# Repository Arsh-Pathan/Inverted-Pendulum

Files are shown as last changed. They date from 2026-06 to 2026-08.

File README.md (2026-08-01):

# Inverted Pendulum Hardware-in-the-Loop (HIL) & Control System

A high-performance **Hardware-in-the-Loop (HIL) Control & Simulation Platform** for single-axis inverted pendulums. Features physical modeling, classical control strategies (PID, LQR, Hybrid Energy Swing-Up), Reinforcement Learning environment (Gymnasium / PPO / SAC), real-time serial telemetry, and a PyQt6 control panel.

---

## 🏛️ Codebase Structure

The project has been cleaned and consolidated into modular packages:

```
Inverted-Pendulum/
├── algorithm/               # Core Control, Environment & GUI Package
│   ├── comms/              # Serial communication protocol & hardware interface
│   ├── gui/                # PyQt6 Desktop GUI & Real-time Telemetry Canvas
│   ├── math/               # Mathematical algorithms & control dynamics
│   │   ├── controllers/    # PID, LQR, Energy Swing-up & Hybrid controllers
│   │   ├── core/           # Telemetry state representation & parsing
│   │   └── envs/           # Gymnasium-compatible simulation environment
│   ├── utils/              # Data logging, CSV storage & configuration utilities
│   └── main.py             # Main entry point for PyQt6 Control Station
├── config/                 # Platform default settings & serial configuration
│   └── default_config.json
├── docs/                   # Mathematical derivations & research documentation
│   ├── math/               # Equations of motion, LQR, energy & RL formulation
│   └── research_paper_formulation.md
├── firmware/               # Microcontroller (ESP32 / Arduino) source code
│   └── esp32_firmware.ino
├── models/                 # Pre-trained RL policies (PPO / SAC weights)
├── rl/                     # Reinforcement Learning training & evaluation scripts
│   ├── evaluate_policy.py  # Run trained policy in simulation
│   ├── train_ppo.py        # PPO training pipeline
│   └── train_sac.py        # SAC training pipeline
├── scripts/                # Diagnostic tools & CLI utilities
│   ├── benchmark_controllers.py
│   ├── calibrate_sensor.py
│   ├── record_telemetry.py
│   └── run_cli_balancer.py
└── tests/                  # Pytest automated test suite
    ├── test_controllers.py
    ├── test_env.py
    ├── test_logger.py
    ├── test_protocol.py
    ├── test_rl.py
    └── test_state.py
```

---

## 🧩 Architectural Component Breakdown

### 1. `algorithm/comms/` (Serial Communication)
- [`protocol.py`](file:///C:/Users/ArshPathan/Projects/Hardware/Inverted-Pendulum/algorithm/comms/protocol.py): Formats outgoing binary/string commands (`M,<pwm>`, `B`, `C`) sent over serial to the ESP32.
- [`serial_client.py`](file:///C:/Users/ArshPathan/Projects/Hardware/Inverted-Pendulum/algorithm/comms/serial_client.py): Handles background thread serial I/O, port auto-detection, and fast non-blocking frame ingestion.

### 2. `algorithm/math/controllers/` (Control Laws)
- [`pid_balancer.py`](file:///C:/Users/ArshPathan/Projects/Hardware/Inverted-Pendulum/algorithm/math/controllers/pid_balancer.py): Implements discrete-time PID control with exponential moving average (EMA) derivative filtering, deadband compensation, and dead-reckoning cart recentering.
- [`lqr_balancer.py`](file:///C:/Users/ArshPathan/Projects/Hardware/Inverted-Pendulum/algorithm/math/controllers/lqr_balancer.py): State-feedback regulator ($u = -Kx$) designed using LQR synthesis on linearized cart-pole dynamics.
- [`swing_up.py`](file:///C:/Users/ArshPathan/Projects/Hardware/Inverted-Pendulum/algorithm/math/controllers/swing_up.py): Energy-pumping controller that injects energy into the system based on total mechanical energy deviation from upright potential energy ($E_{\text{target}} = mgl$).
- [`hybrid_balancer.py`](file:///C:/Users/ArshPathan/Projects/Hardware/Inverted-Pendulum/algorithm/math/controllers/hybrid_balancer.py): Finite-state machine that executes energy swing-up when hanging down and seamlessly hands over to PID/LQR when entering the upright capture basin ($\pm 20^\circ$).

### 3. `algorithm/math/envs/` (Gymnasium Simulation)
- [`inverted_pendulum_env.py`](file:///C:/Users/ArshPathan/Projects/Hardware/Inverted-Pendulum/algorithm/math/envs/inverted_pendulum_env.py): Non-linear equations of motion solver (RK4/Euler integration) equipped with realistic AS5600 encoder quantization, DC motor back-EMF dynamics, and rail limit constraints. Also supports dual-mode Hardware-in-the-Loop execution.

### 4. `algorithm/gui/` & `algorithm/main.py` (Desktop Control Station)
- PyQt6-based control panel ([`main_window.py`](file:///C:/Users/ArshPathan/Projects/Hardware/Inverted-Pendulum/algorithm/gui/main_window.py)) providing live angle/velocity plotting ([`telemetry_canvas.py`](file:///C:/Users/ArshPathan/Projects/Hardware/Inverted-Pendulum/algorithm/gui/telemetry_canvas.py)), parameter tuning controls, and interactive hardware testing.

---

## ⚡ Quick Start

### Running the Control Station GUI
```bash
python algorithm/main.py
```

### Running Automated Unit Tests
```bash
pytest -m "not hardware"
```

### Running CLI Hardware Balancer
```bash
python scripts/run_cli_balancer.py --controller pid
```

### Training Reinforcement Learning Policy (PPO)
```bash
python rl/train_ppo.py --timesteps 100000
```

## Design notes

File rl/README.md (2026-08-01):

# Reinforcement Learning (RL) Autonomous Control Suite

This package provides a professional, end-to-end Reinforcement Learning framework for training, evaluating, and deploying deep neural network policies on the **Inverted Pendulum Platform**.

---

## 🏛️ Architecture & MDP Formulation

By moving the control loop from the ESP32 microcontroller into Python, the physical robotic hardware is directly modeled as a continuous Markov Decision Process (MDP) via our Gymnasium wrapper (`InvertedPendulumEnv`):

*   **State Space ($\mathcal{S} \subset \mathbb{R}^2$):** Continuous observation vector $s_t = [e_\theta, \dot{\theta}]^T$, where $e_\theta \in [-\pi, \pi]$ is the shortest-path angular error from upright equilibrium and $\dot{\theta}$ is angular velocity in rad/s.
*   **Action Space ($\mathcal{A} \subset \mathbb{R}$):** Continuous normalized motor voltage command $a_t \in [-1.0, +1.0]$, linearly mapped to H-bridge PWM duties `[-255, +255]` with stiction deadband compensation.
*   **Reward Function ($\mathcal{R}$):**
    $$R(s_t, a_t) = - \left( e_{\theta, t}^2 + 0.1 \cdot \dot{\theta}_t^2 + 0.001 \cdot a_t^2 \right)$$
    Penalizes angular deviation and velocity while encouraging smooth, low-energy motor actuation.

---

## 📂 Package Overview

*   **`rl_controller.py` (`RLBalancer`)**: Subclass of `BaseController`. Bridges trained neural networks directly into the real-time HIL QThread control loop.
*   **`train_ppo.py`**: Complete training suite for **Proximal Policy Optimization (PPO)** using `Stable-Baselines3`. Features automatic TensorBoard logging and periodic evaluation checkpoints.
*   **`train_sac.py`**: Complete training suite for **Soft Actor-Critic (SAC)**, an off-policy maximum entropy algorithm tailored for continuous robotics tasks.
*   **`evaluate_policy.py`**: Benchmarking tool that runs multi-episode evaluation runs (in simulation or hardware USB mode) and outputs survival times and MSE metrics.

---

## 🚀 Training & Deployment Quickstart

### 1. Install Dependencies
```bash
pip install stable-baselines3[extra] torch torchvision gymnasium
```

### 2. Train an RL Policy (Simulation Mode)
Train PPO for 50,000 steps without needing the hardware connected:
```bash
python rl/train_ppo.py --timesteps 50000 --save-path rl/models/ppo_pendulum.zip
```
Or train Soft Actor-Critic (SAC):
```bash
python rl/train_sac.py --timesteps 50000 --save-path rl/models/sac_pendulum.zip
```
Both scripts also write per-step transition data to CSV under `rl/training_data/`.
Override the destination with `--data-path`, for example:
```bash
python rl/train_ppo.py --timesteps 50000 --data-path rl/training_data/ppo_run_001.csv
```

### 3. Train Directly on Physical Hardware (HIL Mode)
Plug in the ESP32 via USB and train live on the physical cart-pole:
```bash
python rl/train_ppo.py --timesteps 20000 --hil-port COM3 --save-path rl/models/ppo_hardware.zip
```

### 4. Evaluate Trained Policy
Benchmark 10 evaluation episodes:
```bash
python rl/evaluate_policy.py --model rl/models/ppo_pendulum.zip --algo PPO --episodes 10
```

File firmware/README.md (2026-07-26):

# ESP32 Modular Hardware-in-the-Loop (HIL) Endpoint Firmware

This directory contains the industrial-grade, modular C++ firmware for the ESP32 microcontroller powering the **Inverted Pendulum HIL Platform**.

---

## 🏛️ Modular C++ Architecture

To maintain maximum code readability and clean separation of concerns, the firmware is structured into modular C++ classes:

*   **`config.h`**: Centralized definitions for GPIO pin mappings, I2C addresses, LEDC PWM frequencies/resolutions, and default baud rates.
*   **`encoder_driver.h` / `.cpp`**: Encapsulates 400 kHz Fast I2C communication with the AS5600 12-bit magnetic encoder. Handles raw bit extraction, angle conversion, and zero-equilibrium tare calibration.
*   **`motor_driver.h` / `.cpp`**: Manages the TB6612FNG dual H-bridge driver. Configures ESP32 LEDC hardware PWM timers (1 kHz, 8-bit resolution) and implements directional control, coasting, and hard dynamic braking.
*   **`serial_parser.h` / `.cpp`**: High-speed, non-blocking USB serial command parser. Processes ASCII commands in microseconds without stalling sensor streaming.
*   **`esp32_endpoint.ino`**: The clean 50-line main sketch connecting the drivers and scheduling high-frequency microsecond telemetry streaming.

---

## ⚡ Dual ESP32 Arduino Core v2.x / v3.0+ API Support

In major release v3.0.0 (based on ESP-IDF v5.x), Espressif introduced breaking changes to the LEDC hardware PWM API by removing `ledcSetup` and `ledcAttachPin`, and changing `ledcWrite` to accept a GPIO pin number instead of a channel ID.

The `MotorDriver` class in this firmware automatically detects your toolchain's ESP32 Core version via `<esp_arduino_version.h>` preprocessor macros and adapts compilation on the fly:
*   **On ESP32 Core v3.0+ (ESP-IDF v5.x):** Automatically utilizes `ledcAttach(pin, freq, resolution)` and pin-targeted `ledcWrite(pin, duty)`.
*   **On Legacy Core v2.x (ESP-IDF v4.x):** Seamlessly falls back to `ledcSetup(channel, freq, resolution)` and `ledcAttachPin(pin, channel)`.

This guarantees 100% compilation compatibility across modern Arduino IDE 2.x and legacy PlatformIO environments without manual code edits.

---

## 📌 Hardware Pin Mapping

| Component | Signal | ESP32 GPIO | Description |
| :--- | :--- | :--- | :--- |
| **AS5600 Sensor** | I2C SDA | **GPIO 22** | 400 kHz Fast I2C Data |
| **AS5600 Sensor** | I2C SCL | **GPIO 23** | 400 kHz Fast I2C Clock |
| **TB6612FNG Driver**| AIN1 | **GPIO 25** | Direction control line 1 |
| **TB6612FNG Driver**| AIN2 | **GPIO 26** | Direction control line 2 |
| **TB6612FNG Driver**| PWMA | **GPIO 27** | LEDC Channel 0 PWM (0-255) |
| **TB6612FNG Driver**| STBY | **GPIO 33** | Standby enable (Active HIGH) |

---

## 🔌 Serial Command API (115200 Baud)

When connected via USB Serial, the firmware responds to the following newline-terminated commands:

*   `M,<power>`: Apply signed motor voltage in range `[-255, +255]` (e.g. `M,150` or `M,-200`).
*   `F,<speed>`: Spin motor forward at PWM duty cycle `[0, 255]`.
*   `R,<speed>`: Spin motor reverse at PWM duty cycle `[0, 255]`.
*   `B` or `S`: Hard dynamic short-circuit brake on the motor H-bridge.
*   `C`: Open-circuit free-wheel coasting.
*   `T,<rate_hz>`: Change telemetry streaming rate dynamically (`0` to `1000` Hz).
*   `Q`: Query an immediate single angle float reading.
*   `Z`: Execute on-demand tare calibration (measures 100 samples over 1 second and sets hanging zero offset).

---

## 🚀 Building and Uploading

1. Open the Arduino IDE or PlatformIO.
2. Select **ESP32 Dev Module** (or equivalent ESP32 board).
3. Ensure baud rate is set to **115200**.
4. Compile and upload `esp32_endpoint.ino`.
5. Keep the pendulum hanging completely motionless during the ~5.5 second bootup window (2.5s settling + 3s averaging) after reset to establish high-stability hanging zero calibration!

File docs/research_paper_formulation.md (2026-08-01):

# Technical Research Paper Formulation: Host-in-the-Loop Continuous Control and Deep Reinforcement Learning for Underactuated Robotics

This document provides a comprehensive, publication-ready mathematical formulation, stability proof, and systems analysis for researchers preparing academic manuscripts on the **Inverted Pendulum Platform**.

---

## 1. Abstract & Executive Summary

The inverted pendulum is a canonical problem in underactuated control theory, non-linear dynamics, and robotics. Traditional low-cost experimental platforms execute linear stabilization algorithms (such as Proportional-Integral-Derivative, PID) directly on embedded microcontrollers (e.g., Arduino or ESP32) using low-resolution potentiometers or incremental quadrature encoders. This embedded paradigm imposes significant limitations: code recompilation is required for parameter tuning, computational resources restrict algorithm complexity, and direct deployment of modern continuous Reinforcement Learning (RL) policies is infeasible due to limited SRAM and floating-point processing capabilities.

We present a **Python-Hosted Hardware-in-the-Loop (HIL)** architecture that decouples low-level sensor streaming and motor actuation from closed-loop control mathematics. By utilizing an ESP32 microcontroller strictly as an ultra-low latency I/O endpoint over high-speed USB CDC serial (115200 baud) paired with a 12-bit contactless magnetic encoder (AS5600), the system achieves a deterministic closed-loop round-trip latency of $L_{\text{total}} < 2.0\text{ ms}$. This enables real-time execution of classical PID, modern Linear Quadratic Regulator (LQR) state-feedback control, non-linear Lyapunov energy pumping, and deep neural network policies trained via Proximal Policy Optimization (PPO) and Soft Actor-Critic (SAC) directly on a desktop PC host.

---

## 2. Lagrangian Mechanics & Non-Linear Equations of Motion

Consider a planar cart-pole inverted pendulum system consisting of a cart of mass $M$ moving along a horizontal linear track ($x$-axis), with a pendulum rod of length $2l$ (distance from pivot to center of mass $l$) and bob mass $m$ pivoting freely in the vertical plane. Let $\theta$ represent the angle of the pendulum relative to the downward vertical equilibrium ($\theta = 0$ is hanging rest; $\theta = \pi$ is upright unstable equilibrium).

### 2.1 Kinetic and Potential Energy Formulation
The position coordinates of the cart and pendulum bob center of mass (COM) are given by:
$$x_c = x, \quad y_c = 0$$
$$x_m = x + l \sin\theta, \quad y_m = -l \cos\theta$$

Differentiating with respect to time $t$ yields the linear velocities:
$$\dot{x}_c = \dot{x}, \quad \dot{y}_c = 0$$
$$\dot{x}_m = \dot{x} + l \dot{\theta} \cos\theta, \quad \dot{y}_m = l \dot{\theta} \sin\theta$$

The total kinetic energy of the system $T$ is the sum of the translational kinetic energy of the cart and the translational plus rotational kinetic energy of the pendulum bob (where $I = \frac{1}{3}ml^2$ or equivalent moment of inertia about the COM):
$$T = \frac{1}{2} M \dot{x}^2 + \frac{1}{2} m \left( \dot{x}_m^2 + \dot{y}_m^2 \right) + \frac{1}{2} I \dot{\theta}^2$$
$$T = \frac{1}{2}(M + m)\dot{x}^2 + m l \dot{x}\dot{\theta}\cos\theta + \frac{1}{2}\left(I + m l^2\right)\dot{\theta}^2$$

The total potential energy $V$, assuming zero gravitational potential at the cart pivot horizontal plane ($y=0$), is:
$$V = -m g l \cos\theta$$
where $g = 9.81\text{ m/s}^2$ is gravitational acceleration.

### 2.2 Euler-Lagrange Equations of Motion
The Lagrangian of the system is defined as $\mathcal{L} = T - V$:
$$\mathcal{L} = \frac{1}{2}(M + m)\dot{x}^2 + m l \dot{x}\dot{\theta}\cos\theta + \frac{1}{2}\left(I + m l^2\right)\dot{\theta}^2 + m g l \cos\theta$$

Applying the Euler-Lagrange equation for each generalized coordinate $q \in \{x, \theta\}$ with non-conservative forces $Q_x = F - b_x \dot{x}$ (motor driving force minus linear track viscous damping) and $Q_\theta = -b_\theta \dot{\theta}$ (rotational pivot viscous damping):
$$\frac{d}{dt}\left(\frac{\partial \mathcal{L}}{\partial \dot{q}}\right) - \frac{\partial \mathcal{L}}{\partial q} = Q_q$$

1. **For Cart Translation ($q = x$):**
   $$\frac{\partial \mathcal{L}}{\partial \dot{x}} = (M + m)\dot{x} + m l \dot{\theta}\cos\theta, \quad \frac{\partial \mathcal{L}}{\partial x} = 0$$
   $$\frac{d}{dt}\left(\frac{\partial \mathcal{L}}{\partial \dot{x}}\right) = (M + m)\ddot{x} + m l \ddot{\theta}\cos\theta - m l \dot{\theta}^2\sin\theta$$
   $$(M + m)\ddot{x} + m l \ddot{\theta}\cos\theta - m l \dot{\theta}^2\sin\theta + b_x \dot{x} = F$$

2. **For Pendulum Rotation ($q = \theta$):**
   $$\frac{\partial \mathcal{L}}{\partial \dot{\theta}} = m l \dot{x}\cos\theta + (I + m l^2)\dot{\theta}, \quad \frac{\partial \mathcal{L}}{\partial \theta} = -m l \dot{x}\dot{\theta}\sin\theta - m g l \sin\theta$$
   $$\frac{d}{dt}\left(\frac{\partial \mathcal{L}}{\partial \dot{\theta}}\right) = m l \ddot{x}\cos\theta - m l \dot{x}\dot{\theta}\sin\theta + (I + m l^2)\ddot{\theta}$$
   $$(I + m l^2)\ddot{\theta} + m l \ddot{x}\cos\theta - m g l \sin\theta + b_\theta \dot{\theta} = 0$$

Solving the coupled linear system for accelerations $\ddot{x}$ and $\ddot{\theta}$ yields the complete non-linear dynamics equations implemented in our numerical physics simulation (`InvertedPendulumEnv(simulated=True)`):
$$\ddot{\theta} = \frac{(M + m)(m g l \sin\theta - b_\theta \dot{\theta}) - m l \cos\theta \left( F - b_x \dot{x} + m l \dot{\theta}^2 \sin\theta \right)}{(M + m)(I + m l^2) - m^2 l^2 \cos^2\theta}$$
$$\ddot{x} = \frac{(I + m l^2)\left( F - b_x \dot{x} + m l \dot{\theta}^2 \sin\theta \right) - m l \cos\theta (m g l \sin\theta - b_\theta \dot{\theta})}{(M + m)(I + m l^2) - m^2 l^2 \cos^2\theta}$$

---

## 3. State-Space Linearization & Optimal LQR Formulation

To stabilize the pendulum around the unstable upright equilibrium point $(\theta_0 = \pi, \dot{\theta}_0 = 0, x_0 = 0, \dot{x}_0 = 0)$, we define the angular deviation $\phi = \theta - \pi$. Using small-angle approximations $\sin\theta = \sin(\pi + \phi) \approx -\phi$, $\cos\theta = \cos(\pi + \phi) \approx -1$, and neglecting second-order velocity terms ($\dot{\theta}^2 \approx 0$), the linearized equations of motion become:

$$(M + m)\ddot{x} - m l \ddot{\phi} + b_x \dot{x} = F$$
$$(I + m l^2)\ddot{\phi} - m l \ddot{x} - m g l \phi + b_\theta \dot{\phi} = 0$$

Let the state vector be $x = [x, \dot{x}, \phi, \dot{\phi}]^T$ and control input $u = F$. The continuous-time linear state-space representation $\dot{x} = A x + B u$ has system matrices:

$$A = \begin{bmatrix} 0 & 1 & 0 & 0 \\ 0 & -\frac{(I+ml^2)b_x}{p} & \frac{m^2 g l^2}{p} & -\frac{m l b_\theta}{p} \\ 0 & 0 & 0 & 1 \\ 0 & -\frac{m l b_x}{p} & \frac{(M+m)m g l}{p} & -\frac{(M+m)b_\theta}{p} \end{bmatrix}, \quad B = \begin{bmatrix} 0 \\ \frac{I+ml^2}{p} \\ 0 \\ \frac{m l}{p} \end{bmatrix}$$

where the determinant denominator $p = (M+m)(I+ml^2) - m^2 l^2 > 0$.

### 3.1 Controllability Analysis
The Kalman controllability matrix $\mathcal{C} = [B \ AB \ A^2B \ A^3B]$ has full rank ($r = 4$) provided $m l \neq 0$ and $g > 0$. Thus, the linearized system is completely controllable, and any arbitrary pole placement or optimal state-feedback gain matrix $K \in \mathbb{R}^{1 \times 4}$ can be synthesized.

### 3.2 Linear Quadratic Regulator (LQR) Synthesis
We define an infinite-horizon quadratic cost functional penalizing state deviations and control effort:
$$J = \int_{0}^{\infty} \left( x(t)^T Q x(t) + u(t)^T R u(t) \right) dt$$
where $Q = Q^T \ge 0$ is a positive semi-definite state weighting matrix and $R = R^T > 0$ is a positive definite control weight. The optimal control law minimizing $J$ is given by state feedback:
$$u^*(t) = -K x(t) = -R^{-1} B^T P x(t)$$
where $P$ is the unique positive definite symmetric solution to the Algebraic Riccati Equation (ARE):
$$A^T P + P A - P B R^{-1} B^T P + Q = 0$$

In our Python implementation (`LQRBalancer`), we apply the reduced state-feedback law $u = -(k_\theta \phi + k_\omega \dot{\phi})$ around angle equilibrium, utilizing Exponential Moving Average (EMA) low-pass filtering on velocity $\dot{\phi}$ to attenuate 12-bit AS5600 quantization noise.

---

## 4. Non-Linear Lyapunov Energy Pumping (Åström-Furuta Algorithm)

When the pendulum is outside the linear upright capture basin ($|\phi| > 20^\circ$), linear controllers (PID/LQR) saturate and fail to invert the pendulum from hanging rest. We implement an autonomous non-linear energy-pumping controller based on Lyapunov stability theory.

### 4.1 Energy Function Formulation
The total mechanical energy $E$ of the pendulum relative to its hanging rest state ($\theta = 0$) is:
$$E(\theta, \dot{\theta}) = \frac{1}{2} J_0 \dot{\theta}^2 + m g l (1 - \cos\theta)$$
where $J_0 = I + m l^2$ is the moment of inertia about the cart pivot. At the unstable upright equilibrium ($\theta = \pi, \dot{\theta} = 0$), the target potential energy is:
$$E_0 = 2 m g l$$

We define the normalized energy error $\tilde{E} = E - E_0$. Our objective is to design an acceleration control input $u = \ddot{x}$ that drives $\tilde{E} \to 0$.

### 4.2 Lyapunov Stability Proof
Consider the positive definite quadratic Lyapunov function candidate:
$$V(\tilde{E}) = \frac{1}{2} \tilde{E}^2$$
Differentiating $V$ with respect to time yields:
$$\dot{V} = \tilde{E} \dot{E} = \tilde{E} \left( J_0 \dot{\theta} \ddot{\theta} + m g l \dot{\theta} \sin\theta \right)$$
Substituting the rotational equation of motion $J_0 \ddot{\theta} - m g l \sin\theta = -m l u \cos\theta$ (neglecting rotational damping $b_\theta \approx 0$ for energy pumping):
$$\dot{V} = \tilde{E} \dot{\theta} \left( -m l u \cos\theta \right) = -m l u \tilde{E} \dot{\theta} \cos\theta$$

To guarantee $\dot{V} \le 0$ we select the feedback control law
$$u = -k_E \tilde{E} \dot{\theta} \cos\theta, \qquad k_E > 0$$
or, as bounded bang-bang control,
$$u = -u_{\max}\,\text{sign}\left( \tilde{E} \dot{\theta} \cos\theta \right)$$
Substituting the former into $\dot{V} = -m l u \tilde{E}\dot{\theta}\cos\theta$ gives
$$\dot{V} = -m l k_E \left(\tilde{E} \dot{\theta} \cos\theta\right)^2 \le 0$$

Note the leading minus sign in $u$: with $u = +k_E\tilde{E}\dot\theta\cos\theta$ the same
substitution yields $\dot{V} = +mlk_E(\cdot)^2 \ge 0$, i.e. the energy error *grows*. The sign is
what distinguishes convergence from divergence, and the $\tilde{E}$ factor is what makes the law
stop pumping at the target; a pure $\text{sign}(\dot\theta\cos\theta)$ law omits it and spins the
pendulum indefinitely.

Because $\dot{V} \le 0$ with equality only on the set where $\tilde{E} = 0$, $\dot{\theta} = 0$, or
$\cos\theta = 0$, LaSalle's Invariance Principle gives convergence to the largest invariant subset
of that set. This is convergence to the energy manifold $E = E_0$ — **not** convergence to the
upright point itself: the homoclinic orbit $E = E_0$ includes states passing through vertical with
nonzero speed, and the hanging equilibrium $\dot\theta = 0$ is itself invariant. Hence the need for
a separate capture-and-stabilise stage. Once the state enters the upright capture basin $\mathcal{B}_{\text{capture}} = \{ (\theta, \dot{\theta}) : |\theta - \pi| \le \theta_{\text{capture}}, |\dot{\theta}| \le \omega_{\max} \}$, our supervisory `HybridBalancer` transitions control authority from Lyapunov energy pumping to precision LQR/PID stabilization.

---

## 5. Continuous Reinforcement Learning & Markov Decision Process (MDP)

To overcome the challenges of non-linear stiction, track imperfections, and sensor quantization without manual analytical parameter tuning, we formulate inverted pendulum balancing as a continuous Markov Decision Process (MDP) $(\mathcal{S}, \mathcal{A}, \mathcal{P}, \mathcal{R}, \gamma)$.

### 5.1 MDP Specification
*   **State Space ($\mathcal{S} \subset \mathbb{R}^2$):** Continuous observation vector $s_t = [e_\theta, \dot{\theta}]^T$, where $e_\theta \in [-\pi, \pi]$ is shortest-path angular deviation from upright vertical and $\dot{\theta}$ is angular velocity in rad/s.
*   **Action Space ($\mathcal{A} = [-1.0, +1.0]$):** Continuous normalized voltage command. In HIL hardware execution, $a_t$ is linearly mapped to integer PWM duty cycle with deadband friction compensation:
    $$\text{PWM}(a_t) = \text{sign}(a_t) \cdot \left( \text{PWM}_{\min} + \lfloor |a_t| \cdot (\text{PWM}_{\max} - \text{PWM}_{\min}) \rfloor \right)$$
*   **Reward Function ($\mathcal{R}$):**
    To encourage the agent to enter and sustain vertical balance inside the target upright buffer $[179^\circ, 181^\circ]$ ($|e_\theta| \le 1.0^\circ$) while heavily penalizing continuous rotation or spinning ($|\dot{\theta}| > 360^\circ/\text{s}$), the reward function combines an upright holding survival bonus $R_{\text{hold}}$ and a spin penalty $R_{\text{spin}}$ with quadratic tracking costs:
    $$r(s_t, a_t) = R_{\text{hold}}(e_\theta, k) - R_{\text{spin}}(\dot{\theta}) - \left( w_\theta e_\theta^2 + w_\omega \dot{\theta}^2 + w_u a_t^2 \right)$$
    where $k \ge 1$ is the number of consecutive time steps spent continuously balanced within the upright buffer, and:
    $$R_{\text{hold}}(e_\theta, k) = \begin{cases} +10.0 + \min(40.0, \, 0.1 \cdot k) & \text{if } |e_\theta| \le \frac{\pi}{180}\text{ rad } (\pm 1.0^\circ \text{ buffer around } 180^\circ) \\ 0.0 & \text{otherwise} \end{cases}$$
    $$R_{\text{spin}}(\dot{\theta}) = \begin{cases} 50.0 + 0.15\left(|\dot{\theta}| - 360\right) & \text{if } |\dot{\theta}| > 360^\circ/\text{s} \\ 0.0 & \text{otherwise} \end{cases}$$
    with $|\dot\theta|$ in deg/s, so the penalty grows with excess speed rather than being a flat constant.

    A dense shaping term $\cos\theta$ is added, and the quadratic weights are $w_\theta = 2.0$,
    $w_\omega = 0.05$, $w_u = 0.01$ (on the *normalised* action), plus a soft cart-excursion penalty
    near the rail ends. The $\pm1^\circ$ holding bonus alone is unreachable by random exploration —
    it occupies roughly $0.6\%$ of the angular range — so without the $\cos\theta$ shaping the
    gradient is effectively flat and the agent never discovers the balanced region.

> [!IMPORTANT]
> **Reward timing.** $r_t$ is evaluated on $s_{t+1}$, the state resulting from $a_t$. Scoring the
> pre-transition state $s_t$ misattributes credit by one step.

> [!NOTE]
> **Discounting.** At $\Delta t = 10\ \text{ms}$, $\gamma = 0.99$ corresponds to an effective
> horizon of only $\approx 1\ \text{s}$. For sustained balancing, $\gamma = 0.999$ ($\approx 10\ \text{s}$)
> is the better match to the task timescale.
*   **Discount Factor ($\gamma$):** Set to $\gamma = 0.99$ for infinite-horizon continuous stabilization.

### 5.2 Proximal Policy Optimization (PPO) & Soft Actor-Critic (SAC)
We implement two complimentary deep RL paradigms within our training suite (`rl/`):
1.  **On-Policy PPO (`train_ppo.py`):** Optimizes a stochastic actor-critic neural network using the clipped surrogate objective:
    $$L^{\text{CLIP}}(\theta) = \hat{\mathbb{E}}_t \left[ \min\left( r_t(\theta)\hat{A}_t, \text{clip}(r_t(\theta), 1-\epsilon, 1+\epsilon)\hat{A}_t \right) \right]$$
    where $r_t(\theta) = \frac{\pi_\theta(a_t|s_t)}{\pi_{\theta_{\text{old}}}(a_t|s_t)}$ and clipping threshold $\epsilon = 0.2$. PPO ensures monotonic policy improvement without destructive step updates.
2.  **Off-Policy Maximum Entropy SAC (`train_sac.py`):** Maximizes a trade-off between expected reward and policy entropy $\mathcal{H}(\pi(\cdot|s_t))$:
    $$J(\pi) = \sum_{t=0}^{T} \hat{\mathbb{E}}_{(s_t, a_t) \sim \rho_\pi} \left[ r(s_t, a_t) + \alpha \mathcal{H}\left(\pi(\cdot|s_t)\right) \right]$$
    where temperature parameter $\alpha$ is dynamically tuned during training (`ent_coef="auto"`). SAC achieves superior sample efficiency and robust disturbance rejection for physical robotics.

---

## 6. Sim-to-Real (Sim2Real) Transfer & Hardware Latency Modeling

A primary failure mode when deploying simulation-trained neural networks onto physical HIL hardware is the reality gap introduced by serial transport latency and sensor quantization.

In our HIL architecture, the round-trip latency $L_{\text{total}}$ consists of:
$$L_{\text{total}} = T_{\text{I2C}} + T_{\text{FW\_pack}} + T_{\text{USB\_TX}} + T_{\text{Py\_parse}} + T_{\text{Inference}} + T_{\text{USB\_RX}} + T_{\text{PWM}}$$

Order-of-magnitude budget (analytical, **not** yet measured on this rig):
*   $T_{\text{I2C}}$ — AS5600 two-byte read at 400 kHz: $\approx 100\ \mu\text{s}$
*   $T_{\text{USB\_TX/RX}}$ — a $\approx 8$-character ASCII line at 115200 baud is
    $\approx 8 \times 10 / 115200 \approx 700\ \mu\text{s}$ *per direction*, plus USB frame
    scheduling quantised to the $1\ \text{ms}$ host polling interval
*   $T_{\text{Py\_parse}} + T_{\text{Inference}}$ — MLP forward pass under the Qt timer: $\approx 0.3\text{–}1\ \text{ms}$

> [!WARNING]
> **These figures are estimates and must be measured before publication.** Two effects dominate and
> push the realistic round trip toward $3\text{–}5\ \text{ms}$ rather than the $1.45\ \text{ms}$
> previously claimed here: (i) USB CDC transfers are scheduled on $1\ \text{ms}$ host frames in each
> direction, and (ii) the Python control loop is driven by a Qt timer, so its jitter is bounded by
> the GUI event loop rather than by serial throughput. The earlier per-stage numbers were not
> obtained from any instrumentation in this repository.

### 6.1 Sensing and Actuation Limits
Two hardware limits bound achievable performance and should be stated plainly:
*   **Angular quantisation.** The AS5600 is 12-bit over $360^\circ$, i.e. $0.088^\circ$ per LSB.
    Differentiating that at $100\ \text{Hz}$ yields $\approx 8.8^\circ/\text{s}$ of velocity noise per
    LSB — comparable to the velocity deadzone itself, which is why derivative terms require
    low-pass filtering.
*   **Unobserved cart position.** The platform instruments the pendulum pivot only. The cart
    position $x$ and velocity $\dot{x}$ are therefore **not measured**, so the deployed feedback is
    $u = u(\theta, \dot{\theta})$, a partial-state restriction of the four-state LQR derived in
    §3. This suffices to hold the pole vertical but leaves the cart position unregulated: it drifts
    until it reaches a rail end-stop. Closing the loop on all four states — and thus realising the
    LQR gain $K \in \mathbb{R}^{1\times4}$ above — requires adding cart odometry.

**Sim-to-real.** Domain randomisation over latency and sensor noise is a planned mitigation; it is
**not yet implemented** in `InvertedPendulumEnv`, and no zero-shot transfer result has been
demonstrated on this hardware. Claims to that effect should not be made until measured.

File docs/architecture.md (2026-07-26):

# Hardware-in-the-Loop (HIL) System Architecture

This document details the architectural migration of the **Inverted Pendulum Platform** from embedded microcontroller balancing to a high-speed **Python-Hosted Hardware-in-the-Loop (HIL)** control paradigm.

---

## 🏛️ Architectural Evolution

### Why Move Balancing Logic to Python?
In traditional embedded robotics, closed-loop PID algorithms are compiled directly into microcontroller C++ firmware. While deterministic, this approach presents significant bottlenecks for modern research and advanced AI control:
1. **Zero Recompile Friction:** Tuning parameters, modifying non-linear filters, or experimenting with novel control algorithms no longer requires compiling and flashing firmware over USB.
2. **Reinforcement Learning (RL) Native:** Deep Reinforcement Learning agents (e.g., PPO, SAC, DQN via PyTorch, Stable-Baselines3, or Gymnasium) execute within a Python runtime. By turning the ESP32 into an ultra-fast I/O endpoint, physical hardware is directly exposed as an OpenAI Gym / Gymnasium environment without complex bridging layers.
3. **Advanced Telemetry & Diagnostics:** Running the controller on the PC host allows microsecond-precise logging, real-time FFT frequency analysis, and phase-portrait visualization in PyQtGraph without saturating microcontroller memory or serial buffers.

---

## 🔗 System Dataflow & HIL Loop

```mermaid
graph TD
    subgraph Hardware [ESP32 Microcontroller Endpoint]
        AS[AS5600 Magnetic Encoder] -->|400kHz I2C| Read[Sensor Read Endpoint]
        Read -->|100Hz ASCII Telemetry Stream| USB_TX[USB Serial Transmit]
        USB_RX[USB Serial Receive] -->|Parse M, power| HBridge[TB6612FNG H-Bridge Driver]
        HBridge -->|1kHz LEDC PWM| Motor[DC Gearmotor Actuator]
    end

*Note on Hardware PWM Compatibility: The ESP32 endpoint firmware automatically detects your Arduino toolchain version and adapts between legacy ESP32 Core v2.x (`ledcSetup`/`ledcAttachPin`) and modern Core v3.0+ (`ledcAttach`) PWM APIs.*

    subgraph Host [PC Python Control Software]
        USB_TX -->|Raw Angle Float| Reader[QThread Serial Client]
        Reader -->|DirectConnection Signal| Controller[Python Controller Engine]
        
        subgraph Controllers [Swappable Control Modules]
            Controller -->|Select| PID[PID Balancer with EMA Filter]
            Controller -->|Select| RL[Reinforcement Learning Policy]
            Controller -->|Select| OSC[Oscillation Test Controller]
        end
        
        PID -->|Motor Power Output| Writer[Async Command Queue]
        RL -->|Motor Power Output| Writer
        OSC -->|Motor Power Output| Writer
        
        Writer -->|M, power Command| USB_RX
        Reader -->|Ring Buffer Slice| GUI[PyQt6 CAD Dashboard]
    end
```

---

## 🧠 Python Control Algorithms

The host software implements a modular controller architecture where controllers inherit from `BaseController`.

### 1. PID Balancer with Noise Suppression (`PIDBalancer`)
To maintain upright stability without mechanical limit-cycle buzzing or quantization jitter, the Python PID controller implements four essential optimizations:

*   **Exponential Moving Average (EMA) Derivative Filter:**
    The 12-bit magnetic encoder produces quantization noise that causes massive spikes when taking raw numerical derivatives ($\frac{\Delta e}{\Delta t}$). We apply a first-order low-pass EMA filter:
    $$\text{filtered\_derivative}_t = \alpha \cdot \frac{e_t - e_{t-1}}{\Delta t} + (1 - \alpha) \cdot \text{filtered\_derivative}_{t-1}$$
    With $\alpha = 0.08$ at $100\text{ Hz}$, the filter cutoff frequency is $\approx 6.4\text{ Hz}$, completely dampening sensor jitter while preserving phase margin.

*   **Shortest-Path Telemetry Wrapping & Velocity Clamping:**
    While raw AS5600 encoder telemetry streams in the modulo range $[0^\circ, 360^\circ)$, plotting raw angles on time-series charts when hovering around vertical upright ($0^\circ$ or $360^\circ$) causes visual wrap-around artifacts (jumping between $0^\circ$ and $359.9^\circ$) and numerical velocity derivative spikes ($> 19,000^\circ/\text{s}$). The host telemetry processor wraps all angles into the shortest-path range $[-180.0^\circ, +180.0^\circ]$ using $((\theta + 180^\circ) \bmod 360^\circ) - 180^\circ$ and applies velocity clamping ($\pm 2,000^\circ/\text{s}$) to ensure pristine line charts, phase portraits, and peak readouts.

*   **"Catch-the-Fall" Motor Polarity & Direction Reversal:**
    To maintain unstable equilibrium above horizontal ($90^\circ < \theta < 270^\circ$), whenever the pendulum rod falls in one direction, the cart MUST accelerate in that exact same direction to catch the falling center of mass and push the base back under the rod. Because physical DC motor polarity wiring (`M1+`/`M1-`) varies across robot builds, the Control Panel provides an interactive **Reverse Motor Direction** checkbox (`chk_invert_motor`, checked by default) that instantly flips the PWM output sign in software ($u = -u$). This provides 1-click polarity alignment without hardware rewiring.

*   **Dynamic Crossing Inversion:**
    The physical dynamics of a pendulum invert across the horizontal plane ($90^\circ$ and $270^\circ$). Below horizontal, the system is stable and requires opposing torque to dampen swings. Above horizontal, the system is unstable and requires same-direction acceleration to catch the falling center of mass. The controller dynamically checks:
    $$\text{above\_horizontal} = (90^\circ < \theta < 270^\circ)$$
    If true, the control output sign is inverted automatically.

*   **Linear Deadband Compensation:**
    DC gearmotors exhibit static friction (stiction). Sending PWM voltages below a threshold (e.g., duty cycle $< 45$) produces zero physical torque, creating a deadzone where balance is lost. The controller maps control output linearly from the minimum actuation power ($45$) up to maximum power ($255$).

*   **Equilibrium Deadzone Coasting:**
    When the pendulum is within $\pm0.4^\circ$ of vertical and angular velocity is below $6.0^\circ/\text{s}$, the controller commands coasting (`0` power). This prevents the motor from continuously buzzing back and forth across the encoder's least significant bit (LSB).

---

## 🤖 Reinforcement Learning MDP Formulation

For hardware-in-the-loop RL training, the physical setup is modeled as a continuous Markov Decision Process (MDP):

*   **State Space ($\mathcal{S}$):** Continuous vector $s_t = [\theta, \dot{\theta}]$ (or $[x, \dot{x}, \theta, \dot{\theta}]$ when cart encoder is installed).
*   **Action Space ($\mathcal{A}$):** Continuous motor voltage command $a_t \in [-255, 255]$ sent via `M,<power>` endpoint.
*   **Reward Function ($\mathcal{R}$):**
    $$R_t = - \left( (\theta_t - 180^\circ)^2 + 0.1 \cdot \dot{\theta}_t^2 + 0.001 \cdot a_t^2 \right)$$
    Reward is maximized when angular deviation and velocity are zero with minimal control energy expenditure.

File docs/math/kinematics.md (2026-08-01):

# 1. System Kinematics

The first step in deriving the equations of motion for the inverted pendulum is to establish the coordinate system and determine the position and velocity of all masses in the system.

## 1.1 System Parameters and Coordinate Frame

We define our reference frame with the origin $(0,0)$ at the center of the cart's track when the cart is at rest. The horizontal axis is $X$ (positive to the right) and the vertical axis is $Y$ (positive upwards).

*   **$M$**: Mass of the cart (kg)
*   **$m$**: Mass of the pendulum (kg)
*   **$l$**: Distance from the cart's pivot point to the center of mass (CoM) of the pendulum (m)
*   **$x(t)$**: The horizontal position of the cart at time $t$ (m)
*   **$\theta(t)$**: The angle of the pendulum with respect to the vertical upward axis (rad). Thus, $\theta = 0$ corresponds to the pendulum pointing straight up, and $\theta = \pi$ corresponds to the pendulum hanging straight down.

## 1.2 Cart Kinematics

The cart is constrained to move only along the horizontal track. Therefore, its position coordinates are simply:
$$x_{cart} = x$$
$$y_{cart} = 0$$

Taking the time derivative, the velocity of the cart is:
$$v_{cart_x} = \dot{x}$$
$$v_{cart_y} = 0$$

## 1.3 Pendulum Kinematics

The pendulum's center of mass is attached to the cart at a pivot point. The position of this pivot point is exactly $(x, 0)$. 
Using trigonometry, the horizontal distance of the pendulum's CoM from the pivot is $l \sin(\theta)$, and the vertical height of the pendulum's CoM from the pivot is $l \cos(\theta)$.

Thus, the global coordinates of the pendulum's center of mass, $(x_p, y_p)$, are:
$$x_p = x + l \sin(\theta)$$
$$y_p = l \cos(\theta)$$

To find the velocity of the pendulum's center of mass, we differentiate the position coordinates with respect to time $t$. We must use the chain rule since $\theta$ is a function of time $\theta(t)$.

**Horizontal velocity of the pendulum ($v_{px}$):**
$$v_{px} = \frac{d}{dt} x_p = \frac{d}{dt} (x + l \sin(\theta))$$
$$v_{px} = \dot{x} + l \cos(\theta) \dot{\theta}$$

**Vertical velocity of the pendulum ($v_{py}$):**
$$v_{py} = \frac{d}{dt} y_p = \frac{d}{dt} (l \cos(\theta))$$
$$v_{py} = -l \sin(\theta) \dot{\theta}$$

The squared magnitude of the pendulum's velocity ($v_p^2 = v_{px}^2 + v_{py}^2$) will be essential for calculating kinetic energy in the next section:
$$v_p^2 = (\dot{x} + l \cos(\theta) \dot{\theta})^2 + (-l \sin(\theta) \dot{\theta})^2$$
$$v_p^2 = (\dot{x}^2 + 2 l \dot{x} \dot{\theta} \cos(\theta) + l^2 \dot{\theta}^2 \cos^2(\theta)) + (l^2 \dot{\theta}^2 \sin^2(\theta))$$

Factoring out $l^2 \dot{\theta}^2$ from the last two terms:
$$v_p^2 = \dot{x}^2 + 2 l \dot{x} \dot{\theta} \cos(\theta) + l^2 \dot{\theta}^2 (\cos^2(\theta) + \sin^2(\theta))$$

Using the Pythagorean identity $\cos^2(\theta) + \sin^2(\theta) = 1$:
$$v_p^2 = \dot{x}^2 + 2 l \dot{x} \dot{\theta} \cos(\theta) + l^2 \dot{\theta}^2$$

With the kinematics fully described, we can now formulate the energy equations for the system.

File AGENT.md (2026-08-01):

# AGENT.md — Engineering & Architecture Roadmap for Autonomous AI Assistants

This document serves as the canonical system manifest, architectural specification, and operational rulebook for AI agents (e.g., Google Antigravity, Copilot, Cursor) contributing to the **Inverted Pendulum HIL Platform**.

---

## 🏗️ Core Architectural Invariants (DO NOT VIOLATE)

### 1. Python-Hosted Hardware-in-the-Loop (HIL) Separation
*   **ESP32 Firmware (`firmware/esp32_endpoint/`) is Stateless:** The embedded firmware MUST NOT contain any closed-loop control mathematics (no PID, LQR, or neural networks). It functions strictly as a low-latency I/O server streaming AS5600 12-bit magnetic encoder telemetry over USB CDC serial (115200 baud) and applying TB6612FNG H-bridge PWM commands (`[-255, +255]`).
*   **Python Control Station (`algorithm/`) is Closed-Loop Host:** All estimation, noise filtering (EMA), geometry math, and control laws run on the Python PC host inside a thread-safe asynchronous serial loop (`QThread`). Target round-trip control loop latency is $< 2.0\text{ ms}$.

### 2. Geometry & Coordinate Conventions
*   **Upright Equilibrium:** Vertical upright equilibrium is defined as $\theta = 180.0^\circ$ ($\pi$ rad).
*   **Shortest-Path Angle Wrapping:** Angular error $e_\theta = 180.0^\circ - \theta_{raw}$ MUST always be wrapped into the shortest path range $[-180.0^\circ, +180.0^\circ]$ using `while e > 180.0: e -= 360.0; while e < -180.0: e += 360.0`.
*   **Lower Hemisphere Inversion:** When the pendulum drops below horizontal ($\theta \in [0^\circ, 90^\circ) \cup (270^\circ, 360^\circ]$), control sign MUST be inverted relative to upright stabilization to prevent positive feedback acceleration into the ground.

### 3. Actuator Deadband & Motor Safety
*   **Stiction Deadband:** Static friction prevents movement below PWM duty $\approx 35$. Controllers apply a smooth dead-zone bias: tiny commands coast, medium commands ramp into the bias, and large commands saturate at `[-255, +255]`.
*   **Hard Clamping:** Never emit motor commands outside integer range `[-255, +255]`.

---

## 📂 Repository Tree & Module Responsibility

```text
Inverted-Pendulum/
├── config/default_config.json       # Persisted serial, encoder, PID gains, & safety limits
├── docs/                            # Deep-dive architecture, wiring schematics, & research papers
├── firmware/esp32_endpoint/         # Modular C++ drivers (AS5600 I2C, TB6612 PWM, Serial Parser)
├── models/                          # FreeCAD assembly and 3MF/STL/G-code 3D print assets
├── algorithm/                       # Python HIL Control Station
│   ├── comms/                       # Thread-safe SerialClient & protocol formatters (M, F, R, B, C, T, Q, Z)
│   ├── math/controllers/            # Swappable engines: PIDBalancer, LQRBalancer, SwingUp, Hybrid, Oscillation
│   ├── math/core/                   # Type-safe PendulumState dataclass & event definitions
│   ├── math/envs/                   # InvertedPendulumEnv(gym.Env) supporting both HIL USB & non-linear Sim
│   └── gui/                         # Premium CAD aesthetic PyQt6 / PyQtGraph dashboard & cards
├── rl/                              # Reinforcement Learning Suite
│   ├── rl_controller.py             # RLBalancer: deploys trained .zip policies into HIL serial loop
│   ├── train_ppo.py                 # Proximal Policy Optimization (PPO) training script
│   ├── train_sac.py                 # Soft Actor-Critic (SAC) continuous training script
│   └── evaluate_policy.py           # Multi-episode evaluation & trajectory benchmarking CLI
├── scripts/                         # Research CLI tools (benchmark_controllers, record_telemetry, calibrate)
└── tests/                           # 19 comprehensive automated unit & integration tests
```

---

## 🛠️ Operational Command Reference for AI Agents

When developing, debugging, or verifying changes, always utilize the following standard verification commands:

### 1. Run Automated Test Suite (MANDATORY BEFORE COMMITS)
Always ensure 100% test pass rate across protocol formatters, state wrapping, control laws, RL envs, and loggers:
```bash
python -m unittest discover tests -v
```

### 2. Verify Non-Linear Control Laws (Offline Physics Sim)
Benchmark settling time, peak error, and energy expenditure across PID, LQR, and Hybrid controllers:
```bash
python scripts/benchmark_controllers.py
```

### 3. Reinforcement Learning Workflows
```bash
# Train PPO in offline non-linear simulation for 50,000 steps
python rl/train_ppo.py --timesteps 50000 --save-path rl/models/ppo_pendulum.zip

# Train SAC in offline simulation
python rl/train_sac.py --timesteps 50000 --save-path rl/models/sac_pendulum.zip

# Evaluate a trained checkpoint (returns mean survival time and MSE)
python rl/evaluate_policy.py --model rl/models/ppo_pendulum.zip --algo PPO --episodes 10
```

### 4. Hardware-in-the-Loop (HIL) CLI Diagnostics
```bash
# Verify USB serial endpoints and command response
python scripts/test_serial_endpoints.py

# Record 10 seconds of high-speed sensor telemetry to CSV
python scripts/record_telemetry.py --duration 10.0

# Run headless closed-loop HIL balancer in terminal
python scripts/run_cli_balancer.py
```

---

## 📋 Git Workflow & Commit Convention

AI contributors MUST adhere to **Conventional Commits** formatting to maintain a clean git history:
*   `feat: ...` — New features, algorithms, or CLI utilities.
*   `fix: ...` — Bug fixes or sign inversion corrections.
*   `refactor: ...` — Code restructuring without behavior changes.
*   `docs: ...` — Documentation, README, or research paper updates.
*   `test: ...` — Adding or updating test suites.
*   `chore: ...` — Dependency updates or build config maintenance.

**Rule:** Every commit MUST be atomic, self-contained, and accompanied by a passing unit test run (`python -m unittest discover tests -v`).

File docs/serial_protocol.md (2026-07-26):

# ESP32 Hardware Endpoint Serial Protocol

The ESP32 firmware in this repository operates as a **deterministic hardware I/O endpoint**. It exposes serial commands to control motor actuation and streams calibrated AS5600 magnetic encoder telemetry to the PC host.

---

## 📡 Communication Specs

*   **Baud Rate:** `115200` (configurable up to `921600`)
*   **Data Bits:** `8`, **Parity:** `None`, **Stop Bits:** `1` (`8N1`)
*   **Line Termination:** ASCII Newline (`\n`) or Carriage Return + Newline (`\r\n`)
*   **Telemetry Streaming Rate:** Default `100 Hz` (10 ms interval), configurable from `1 Hz` to `1000 Hz`.

---

## 📥 Host-to-Target Commands (PC $\rightarrow$ ESP32)

Send these commands over USB serial to control the physical hardware. Commands are evaluated immediately in the ESP32 main loop.

| Command Syntax | Parameters | Description | Example |
| :--- | :--- | :--- | :--- |
| `M,<power>` | `<power>`: Integer in range `[-255, +255]` | Directly set motor power and direction. Positive values spin forward, negative values spin reverse, and `0` coasts. | `M,150`<br>`M,-120`<br>`M,0` |
| `F,<speed>` | `<speed>`: Integer in range `[0, 255]` | Spin motor forward at specified PWM speed. | `F,200` |
| `R,<speed>` | `<speed>`: Integer in range `[0, 255]` | Spin motor reverse at specified PWM speed. | `R,200` |
| `B` or `S` | *None* | **Hard Brake:** Short-circuits the H-bridge motor terminals to stop cart motion immediately. | `B` |
| `C` | *None* | **Coast:** Open-circuits the H-bridge, allowing the motor and cart to free-wheel smoothly. | `C` |
| `T,<rate_hz>` | `<rate_hz>`: Integer in range `[0, 1000]` | Set the streaming frequency for sensor telemetry. Setting `0` pauses streaming. | `T,200`<br>`T,0` |
| `Q` | *None* | **Query Single Reading:** Requests an immediate single angle telemetry float from the encoder. | `Q` |
| `Z` | *None* | **Tare / Zero Calibrate:** Coasts motor and samples 500 readings over 2 seconds to set the hanging vertical zero reference offset. | `Z` |

---

## 📤 Target-to-Host Telemetry (ESP32 $\rightarrow$ PC)

When streaming is enabled (default `100 Hz`), the ESP32 outputs ASCII-formatted floating point numbers representing the current angular deviation in degrees:

```text
0.02
-0.15
1.42
12.85
```

### Telemetry Angle Conventions:
*   `0.00°`: Bottom hanging equilibrium (calibrated during bootup or via `Z` command).
*   `±180.00°`: Vertical inverted upright position (target balancing point).
*   **Resolution:** 12-bit magnetic encoder (`360° / 4096 counts ≈ 0.0879°` per LSB).

---

## ⚡ Latency & Timing Budget

In Hardware-in-the-Loop (HIL) operation over USB serial at `115200` baud:
*   **Telemetry Frame Size:** ~8 bytes (`"-179.50\r\n"`) $\rightarrow$ Transmission duration $\approx 0.7\text{ ms}$.
*   **Command Frame Size:** ~6 bytes (`"M,-150\n"`) $\rightarrow$ Transmission duration $\approx 0.5\text{ ms}$.
*   **Total Serial Round-Trip Time:** $\approx 1.2\text{ ms}$.
*   **Host Python Processing:** $\approx 0.1\text{ ms}$ (using optimized numpy / direct Qt signal callbacks).

This ensures total closed-loop control latency remains **under 2.0 ms**, easily satisfying Nyquist stability criteria for an inverted pendulum with a natural frequency of ~2–3 Hz.

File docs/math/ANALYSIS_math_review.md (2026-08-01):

# Math & Control Review — Findings and Fixes

Review of the control/RL mathematics against the physical rig (single AS5600 on the pendulum
pivot, TB6612FNG-driven belt cart on a ~0.4 m rail, ESP32 streaming angle at 100 Hz).

Every claim below was verified by running the code, not by inspection alone.

---

## 0. TL;DR — why it drove the wrong way

**Root cause: two contradictory sign conventions were mixed inside every control law.**

`PendulumState` exposed only `error_from_upright = 180 - angle_dev`. But the reported `velocity`
is `d(angle_dev)/dt`. So:

$$\texttt{error\_from\_upright} = -\theta, \qquad \texttt{velocity} = +\dot{\theta}$$

The position term and the velocity term had **opposite signs**. Consequences:

1. The proportional term drove the cart *away* from the fall (it must drive *toward* it).
2. The derivative/`k_omega` term became **positive velocity feedback** — actively anti-damping.

This is exactly the reported symptom: *"it moves in the opposite direction of balancing."*

Fixed by adding a single canonical coordinate, `theta_from_upright` ($\theta = \texttt{angle\_dev} - 180$,
wrapped), used by every controller, with **positive** gains on both terms.

Empirical check (8° initial tilt, closed loop in the corrected simulator):

| Convention | Result |
|---|---|
| `u = -k\theta` (old) | diverges to 46° in 0.2 s |
| `u = +k\theta` (new) | holds the pole at 8°, no divergence |

---

## 1. Simulator physics were wrong in three independent ways

The old `step()` integrated

```
accel = (m*g*l*sin(theta) - b*vel + torque) / (m*l*l)
```

**(a) Wrong actuation coupling — the critical one.** The motor entered as an *additive torque*
`+torque`. The real pendulum is unactuated at the pivot; it is driven only through the cart's
inertial reaction:

$$J\ddot{\theta} = mgl\sin\theta \;-\; ml\,\ddot{x}\cos\theta \;-\; b\dot{\theta}$$

Note the **minus** sign. The old model inverted the input coupling, so any controller tuned
against it pushes the wrong way on hardware — the simulator was *rewarding* the very sign error
described in §0.

**(b) Wrong inertia.** Used $J = ml^2$ (point mass) while `docs/math/energy.md` derives
$J = \frac{4}{3}ml^2$ for a uniform rod with COM at $l$ — a 33 % error.

**(c) No cart state at all.** $x$ and $\dot{x}$ were never simulated, so rail limits and cart
drift — the dominant real-world failure mode — were invisible to training.

Also fixed: explicit → **semi-implicit Euler** (much better behaved for oscillatory systems), and
the state vector is now $[x, \dot{x}, \theta, \dot{\theta}]$ with an inelastic end-stop.

---

## 2. The `UnboundLocalError` — HIL mode could never run

In the old `step()`, `theta_err` was assigned *only* inside the `if self.simulated:` branch, but
the reward block below used it unconditionally. Confirmed by direct execution:

```
HIL step FAILED -> UnboundLocalError: cannot access local variable 'theta_err'
```

So **hardware-in-the-loop RL crashed on its first step, always.** Compounding it,
`SerialClient` never defined `last_angle`/`last_velocity`, which the HIL path read via
`getattr(..., default)` — it would have silently fed constants even without the crash. Both are
now implemented (wrap-aware velocity included).

---

## 3. Reward was computed on the *pre-step* state

The reward block read `theta_err`/`vel` — the values captured *before* integration. Every reward
and termination signal was attributed to the wrong transition, teaching a one-step-shifted
objective. Reward is now computed from the post-step state.

## 4. Reward shaping was unlearnable

The only positive signal was a bonus inside $|\theta| \le 1^\circ$ — about **0.6 %** of the state
range. A fresh policy essentially never lands there, so the gradient was flat and PPO/SAC had
nothing to climb. Added a dense $\cos\theta$ term ($+1$ upright → $-1$ hanging), rebalanced the
quadratic weights, and added a soft cart-excursion penalty.

## 5. Discount horizon was ~10× too short

At $dt = 10$ ms, $\gamma = 0.99$ is an effective horizon of $\frac{dt}{1-\gamma} = 1.0$ s — shorter
than the behaviour being learned. Now $\gamma = 0.999$ (≈10 s).

## 6. `terminated` made swing-up impossible

Termination fired at $|\theta| > 45^\circ$ **unconditionally**. A swing-up episode starts hanging
at $180^\circ$, so it terminated on step 1 — the swing-up task could never train. Now gated on
`task="balance"`.

---

## 7. Swing-up had no energy target (it could only spin)

The law was $u = \mathrm{sign}(\dot\theta\cos\theta)P_{max}$ — **no energy-error term**. It pumps
energy without bound and never stops, so the pendulum spins forever. (The RL "spin penalty" was
treating this symptom.) The Åström–Furuta law needs $\tilde{E} = E - E_{top}$:

$$u = -k_E\,\tilde{E}\,\dot\varphi\cos\varphi \;\Rightarrow\; \dot{V} = -mlk_E(\tilde{E}\dot\varphi\cos\varphi)^2 \le 0$$

which pumps below the target, **brakes above it**, and vanishes at it. Also added a kick-start
(the law is identically zero at exact rest) and correct $J = \frac{4}{3}ml^2$.

Result: closest approach to upright went from "spins forever" to **0.00°**, entering the ±25°
capture basin in 1.6 s.

`HybridBalancer.compute_action` also hardcoded `velocity=0.0`, which blinded the energy law to
swing direction — it now estimates velocity by differencing.

---

## 8. Deadband mapping discarded most of the control range

```python
speed = min_power + int(abs_output * (max_power - min_power) / 255.0)
```

`abs_output` is a gain-weighted quantity in *degrees*, divided by an unrelated 255. At `kp=15`,
a 5° error gives `output=75` → mapped to only ~62/255. It also never clamped the normalized
fraction to 1.0. Now explicitly saturating: `min(1.0, abs_output/255.0)`.

## 9. GUI reward inflated control cost by ~65,000×

```python
0.001 * (norm_action * 255.0)**2
```

`norm_action` was already divided by 255, then multiplied straight back — a factor of $255^2$
versus the RL env's `0.001 * norm_action**2`. The effort term swamped every other component, so
the dashboard's reward readout bore no relation to the training objective.

## 10. `benchmark_controllers.py` was dead code

Called `np_array(...)` **before its definition** (module-level `NameError` on every run), wrote
only `env.state` while the integrator read a separate vector, double-negated velocity to
compensate for the §0 sign bug, and judged settling on stale pre-step velocity. All fixed; it now
runs and reports settling times of 0.60–0.92 s.

## 11. Firmware header was corrupted (would not compile)

```c
#define AS5600_REG_ANGLE_L    0x0F333333333333333333333333333333333333333333333
```

An editing accident left a 45-digit integer literal — the firmware could not build. Restored to
`0x0F`.

---

## 12. STRUCTURAL LIMIT — this rig cannot hold position with one sensor

This is the most important finding, and no amount of tuning fixes it.

The platform measures **only the pendulum angle**. The cart-pole system has four states
$[x, \dot{x}, \theta, \dot{\theta}]$; `docs/research_paper_formulation.md` correctly derives a
four-state LQR with $K \in \mathbb{R}^{1\times4}$ — but the deployed law feeds back only
$[\theta, \dot{\theta}]$. Angle-only feedback can hold the pole vertical while the cart position
goes unregulated, so any residual tilt bias makes the cart drift until it hits the end-stop.

Measured on the corrected simulator (0.4 m rail, 8° initial tilt):

| Feedback | Outcome |
|---|---|
| $[\theta,\dot\theta]$ only | pole held within 8°, but **hits rail end-stop in 0.89 s** |
| $+\,[x,\dot{x}]$ added | **stable for the full 15 s**, $\theta \to 0.00°$, cart returns to 0.000 m |

The pole was never the problem — the **cart** was. To balance for more than ~1 s of rail travel,
add cart odometry (motor-shaft encoder or belt encoder) and close the loop on all four states.
This is a hardware requirement, not a tuning issue.

---

## 12b. Round 2 — the overshoot ("reaches 180° then falls back")

Follow-up investigation of the reported overshoot. Reproduced by modelling the *full* live
signal chain (12-bit quantisation → GUI EMA → controller EMA → `min_power` deadband). Three
independent causes, all measured:

### (a) Cascaded filter lag ≈ one instability time constant

An EMA with factor $\alpha$ at 100 Hz has time constant $\frac{1-\alpha}{\alpha}\,dt$:

| Filter | $\alpha$ | Lag |
|---|---|---|
| GUI velocity EMA | 0.20 | 40 ms |
| Controller derivative EMA | 0.08 | **115 ms** |
| **Cascade** | | **≈155 ms** |

The pendulum's own instability time constant is $\sqrt{J/mgl} = 148$ ms. So the **damping term
— the one that prevents overshoot — arrived a full time constant late.** The controller was
reacting to where the pole *was*, not where it is. Fixed: GUI EMA → 0.55, controller
`alpha` → 0.45 (single dominant filter instead of two cascaded ones).

### (b) The equilibrium deadzone removed the corrections that prevent overshoot

`equilibrium_deadzone_deg = 0.4` zeroed the command whenever the pole was within 0.4° of
upright — exactly the small early corrections that arrest an incipient fall. Measured effect
(6° start): peak error **14.40° with** the deadzone vs **6.00° without**. Now defaults to 0.0.

### (c) The real killer: it was never the pole, it was the cart

Instrumenting the failure shows the pole is held near 0.5° for *seconds* while the cart
accelerates away monotonically:

```
step   theta   cart_v   cart_x   pwm
  80    0.30    0.352    0.266   -48
 320    0.61    0.533    1.331    63
 480    1.77    0.770    2.343    78
 640   11.92    2.163    4.366   255 SAT   <- saturated, pole now unrecoverable
 720 -122.73                              <- fallen
```

The pole angle only diverges *after* the cart saturates. The "overshoot" is the end-stop
impact from §12, not a tuning problem.

### The fix: dead-reckoned cart observer (no new hardware)

We can't *measure* cart velocity — but we know every PWM command we sent. So the missing two
LQR states are recovered by integrating the actuator model
$$\dot{v} = a_{cmd} - c\,v, \qquad a_{cmd} = \tfrac{u}{255}\,\ddot{x}_{max}$$
and fed back as $k_v\hat{v} + k_x\hat{x}$ (`k_cart_v=150`, `k_cart_x=200`).

Results on the **real 0.4 m rail**, 30 s, full quantisation + filter chain:

| Configuration | Result |
|---|---|
| Old config (α=.08, deadzone, no cart term) | **hits rail in 0.8 s** |
| New `PIDBalancer` defaults | **holds 30 s**, peak 6.00°, final 0.13°, cart at −0.000 m |
| New `LQRBalancer` defaults | **holds 30 s**, peak 6.00°, final 0.09°, cart at −0.000 m |

Robustness — the estimator assumes $\ddot{x}_{max}=6, c=2$; the plant was varied:

| Plant | Result |
|---|---|
| $\ddot{x}_{max}$ 3.0 → 12.0 (0.5×–2×) | all hold 30 s |
| $c$ = 0.8 → 4.0 | all hold 30 s |

So the observer does **not** need accurate calibration — it only has to be roughly right to
cancel the drift. Recovery envelope is now ≈±10° (15°+ still exceeds the rail's ability to
recover, which is a genuine physical limit of a 0.4 m track).

> [!NOTE]
> This *reduces* but does not eliminate the §12 recommendation. Dead-reckoning has no feedback,
> so it cannot observe belt slip, wheel slip, or a stalled motor. A real cart encoder remains
> the robust solution; this makes the existing hardware work in the meantime.

---

## 13. Documentation corrections

Verified **correct** (left alone): the Lagrangian derivation in `kinematics.md`/`energy.md`/
`equations_of_motion.md`, and the linearized state-space matrices in
`state_space_linearization.md` — I checked the latter numerically against a direct solve of the
coupled equations (max error $6\times10^{-14}$).

Corrected:
- **Lyapunov proof sign error** (`research_paper_formulation.md` §4.2): the law was written
  $u = +k_E\tilde{E}\dot\theta\cos\theta$, which gives $\dot{V} \ge 0$ — divergence. Needs the
  minus sign. Also softened the LaSalle conclusion: convergence is to the energy manifold
  $E = E_0$, **not** to the upright point (the hanging equilibrium is in the same invariant set).
- **Fabricated latency measurements**: the "measured empirical timing across 10,000 samples"
  (1.45 ms total) is not produced by any instrumentation in this repo. A single 8-char line at
  115200 baud is ~700 µs *per direction* before USB's 1 ms frame scheduling, so the realistic
  round trip is 3–5 ms. Relabelled as estimates with a warning to measure before publishing.
- **Unsupported sim2real claim**: domain randomisation over latency/noise is described as
  implemented and achieving "zero-shot transfer." It is not implemented at all. Marked as planned.
- **Reward function mismatch**: the paper's spin penalty ($+20$ flat) didn't match the code
  ($50 + 0.15\Delta$), nor did the weights. Synced.
- **Inertia inconsistency** in `controller_implementations.md` ($ml^2$ vs $\frac{4}{3}ml^2$).

---

## Verification

All 27 tests pass. Tests that encoded the old inverted convention were rewritten, and new ones
added for: the catch-the-fall sign law, velocity damping polarity, swing-up energy targeting
(pumps below / stops at target), kick-start from rest, and swing-up non-termination while hanging.

## Recommended next steps

1. **Add cart odometry** (§12) — the single highest-value change; without it, sustained balance is
   not achievable on a 0.4 m rail.
2. Confirm the physical constants (`m`, `l`, `max_cart_accel`, `cart_damping`) against the real
   hardware; they are currently plausible estimates, and `max_cart_accel = 6.0 m/s²` in particular
   should be measured.
3. Measure true round-trip latency, then add matching domain randomisation before trusting sim2real.
4. Retrain from scratch — every previously saved policy learned against inverted input coupling
   and a shifted reward, so old checkpoints are not salvageable.

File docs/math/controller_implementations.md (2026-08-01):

# 6. Controller Implementations and Simulation Math

Beyond the foundational physical derivations, the project uses specific mathematical implementations for its controllers, filters, and software physics simulation. This document details the exact mathematics used in the `algorithm/math/controllers` and `algorithm/math/envs` modules.

## 6.1 LQR Balancer (`lqr_balancer.py`)

The Linear Quadratic Regulator (LQR) uses the linearized state-space matrices derived previously to find an optimal state-feedback gain matrix $K$.

### Control Law
The implemented control law calculates the required motor power from the signed tilt and angular velocity:
$$u = k_\theta \cdot \theta + k_\omega \cdot \dot{\theta}_{filtered}$$

**Sign convention (critical).** $\theta$ is `PendulumState.theta_from_upright`, defined as
$$\theta = \mathrm{wrap}(\texttt{angle\_dev} - 180^\circ) \in [-180^\circ, +180^\circ]$$
so $\theta = 0$ is upright and $\dot{\theta}$ (the reported angular velocity) is *exactly* the
time derivative of $\theta$. Both gains are **positive**: to arrest a fall toward $+\theta$ the
cart must accelerate toward $+\theta$ as well ("catch-the-fall"), because the pendulum is
driven only through the pivot reaction term $-m l \ddot{x}\cos\theta$.

> [!WARNING]
> The legacy property `error_from_upright` equals $180^\circ - \texttt{angle\_dev} = -\theta$.
> Mixing it with the raw `velocity` field combines two opposite sign conventions, which turns
> the $k_\omega$ term into *positive* velocity feedback and drives the cart away from the fall.
> Use `theta_from_upright` in all control laws.

### Cart-Position Observability Limit
The physical rig instruments the **pendulum pivot only** (a single AS5600); there is no cart
position encoder. The law above therefore feeds back just $[\theta, \dot{\theta}]$, which can
hold the pole vertical but cannot regulate where the cart sits. Any residual tilt bias makes
the cart drift steadily in one direction until it reaches the end of the rail. Empirically, on
the simulated 0.4 m track, angle-only feedback keeps the pole within $8^\circ$ yet hits the
end-stop in $\approx 0.9\ \text{s}$, whereas adding cart terms
$$u = k_\theta\theta + k_\omega\dot\theta + k_x x + k_v \dot{x}$$
holds both the pole and the cart indefinitely. Full four-state stabilization of this platform
requires adding a cart position sensor (belt encoder or motor-shaft odometry).

### Exponential Moving Average (EMA) Velocity Filter
To reduce noise from the sensor readings, the LQR controller applies an Exponential Moving Average filter (a first-order discrete low-pass filter) to the angular velocity before using it in the control law:
$$\dot{\theta}_{filtered, t} = \alpha \cdot \dot{\theta}_{raw, t} + (1 - \alpha) \cdot \dot{\theta}_{filtered, t-1}$$
Where $\alpha \in (0, 1]$ is the smoothing factor (e.g., $0.08$).

---

## 6.2 Energy Swing-Up Controller (`swing_up.py`)

When the pendulum is hanging down, linear controllers like LQR fail. Instead, we use a non-linear energy-pumping law based on the Åström-Furuta Lyapunov strategy to add kinetic energy until the pendulum enters the top "capture basin".

### Energy Pumping Law
Let $\varphi$ be measured from the **hanging** equilibrium ($\varphi = 0$ hanging, $\varphi = \pm\pi$
upright), and let $J = \frac{4}{3}ml^2$ be the moment of inertia about the pivot. The energy
relative to hanging rest and its upright target are
$$E = \tfrac{1}{2}J\dot{\varphi}^2 + mgl\left(1 - \cos\varphi\right), \qquad E_{top} = 2mgl$$

With the energy error $\tilde{E} = E - E_{top}$ and Lyapunov candidate $V = \tfrac{1}{2}\tilde{E}^2$,
the implemented law is
$$u = -k_E\,\tilde{E}\,\dot{\varphi}\cos\varphi$$
which yields $\dot{V} = -k_E\left(\tilde{E}\dot{\varphi}\cos\varphi\right)^2 \le 0$, so $E \to E_{top}$.

The $\tilde{E}$ factor is what makes this converge: it **pumps** energy while $E < E_{top}$,
**brakes** once $E > E_{top}$, and goes to zero at the target.

> [!WARNING]
> A bare $u = \mathrm{sign}(\dot{\varphi}\cos\varphi)\,P_{max}$ law (no $\tilde{E}$ term) has no
> notion of "enough energy" and pumps without bound, so the pendulum spins continuously instead
> of arriving at the top with $\dot{\varphi} \approx 0$.

Because the law is identically zero at exact rest ($\dot\varphi = 0, \varphi = 0$), a small
fixed kick is applied to break away from the hanging equilibrium.

---

## 6.3 Numerical Simulation Physics (`inverted_pendulum_env.py`)

For the RL environment and offline testing, the continuous non-linear differential equations are integrated over discrete time steps $\Delta t$ (e.g., 10ms) using the Euler integration method.

### State Update Equations
The simulator state is $[x, \dot{x}, \theta, \dot{\theta}]$, where $\theta$ is the deviation from
upright. The action $a \in [-1, 1]$ commands a cart acceleration
$a_{cart} = a\,\ddot{x}_{max}$, and the realised cart acceleration after rail drag is
$$\ddot{x} = a_{cart} - b_c \dot{x}$$

The pendulum is actuated **only** through the pivot, so its rotational equation about the pivot is
$$J\ddot{\theta} = mgl\sin\theta - ml\,\ddot{x}\cos\theta - b\,\dot{\theta},
\qquad J = \tfrac{4}{3}ml^2$$

Two corrections versus the earlier formulation:
1. **Inertia.** $J = \frac{4}{3}ml^2$ for a uniform rod whose COM is at $l$ (consistent with
   `energy.md`), not the point-mass $ml^2$ — a 33% error in the inertia.
2. **Actuation sign.** The cart enters as $-ml\ddot{x}\cos\theta$. Near upright
   ($\cos\theta \approx 1$) a *positive* cart acceleration *reduces* a positive tilt. Modelling
   the input as an additive $+\tau_{motor}$ inverts this coupling, so a controller tuned against
   that model pushes the cart the wrong way on real hardware.

### Semi-Implicit Euler Integration
Velocities are advanced first, then positions using the *updated* velocity (semi-implicit /
symplectic Euler), which is markedly more stable than explicit Euler for oscillatory systems:
$$\dot{x}_{t+1} = \dot{x}_t + \ddot{x}_t\Delta t, \qquad x_{t+1} = x_t + \dot{x}_{t+1}\Delta t$$
$$\dot{\theta}_{t+1} = \dot{\theta}_t + \ddot{\theta}_t \Delta t, \qquad \theta_{t+1} = \theta_t + \dot{\theta}_{t+1}\Delta t$$

Reaching a rail end-stop is treated as a fully inelastic collision ($\dot{x} \to 0$).

---

## 6.4 RL Environment Reward Function

The reward function $R_t$ calculated at every step in the `InvertedPendulumEnv` combines discrete conditional bonuses/penalties with continuous quadratic costs.

### 1. Upright Holding Bonus
If the pendulum is balanced within $\pm 1.0^{\circ}$ (the "upright buffer"), a time-scaling bonus is applied to encourage stability:
$$Bonus_t = 10.0 + \min(40.0, 0.1 \times \text{frames\_held})$$

### 2. High-Speed Spin Penalty
To prevent the agent from cheating the system by spinning the pendulum continuously, a severe penalty is applied if $|\dot{\theta}| > 360^{\circ}/s$:
$$Penalty_t = \begin{cases} 
      50.0 + 0.15 \times (|\dot{\theta}| - 360) & \text{if } |\dot{\theta}| > 360 \\
      0 & \text{otherwise}
   \end{cases}
$$

### 3. Dense Shaping Term
The $\pm 1^\circ$ holding bonus is far too narrow to be discovered by exploration on its own — a
randomly initialised policy essentially never lands inside it, so the bonus provides no gradient.
A dense term supplies a usable slope from anywhere in the state space:
$$Shaping_t = \cos\theta \in [-1, +1]$$
which is $+1$ upright, $0$ horizontal, and $-1$ hanging.

### 4. Continuous Cost Function
A quadratic cost penalises tilt, spin, control effort, and cart excursion toward the rail ends:
$$Cost_t = 2.0\,\theta^2 + 0.05\,\dot{\theta}^2 + 0.01\,u_{norm}^2 + 5.0\left(\max\left(0, |x| - 0.8\,x_{lim}\right)\right)^2$$
where $u_{norm} \in [-1, 1]$ is the normalised action, $\theta$ and $\dot\theta$ are in **radians**
and rad/s, and $x_{lim}$ is the rail half-length.

**Total Reward:**
$$R_t = Shaping_t + Bonus_t - Penalty_t - Cost_t$$

> [!IMPORTANT]
> The reward is evaluated on the state the action **produced** (post-step), not the state it was
> chosen in. Scoring the pre-step state credits every reward to the wrong transition and makes the
> value function learn a shifted objective.

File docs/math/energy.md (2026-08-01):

# 2. System Energy

To use the Euler-Lagrange method, we need the total kinetic energy ($T$) and the total potential energy ($V$) of the system.

## 2.1 Kinetic Energy ($T$)

The total kinetic energy of the system is the sum of the kinetic energy of the cart and the kinetic energy of the pendulum.
$$T = T_{cart} + T_{pendulum}$$

### Kinetic Energy of the Cart
The cart only undergoes translational motion. Its kinetic energy is:
$$T_{cart} = \frac{1}{2} M v_{cart}^2 = \frac{1}{2} M \dot{x}^2$$

### Kinetic Energy of the Pendulum
The pendulum undergoes both translational motion (its center of mass moves) and rotational motion (it rotates around its center of mass).

1.  **Translational Kinetic Energy:**
    $$T_{p, trans} = \frac{1}{2} m v_p^2$$
    From our kinematics derivation ($v_p^2 = \dot{x}^2 + 2 l \dot{x} \dot{\theta} \cos(\theta) + l^2 \dot{\theta}^2$), this is:
    $$T_{p, trans} = \frac{1}{2} m (\dot{x}^2 + 2 l \dot{x} \dot{\theta} \cos(\theta) + l^2 \dot{\theta}^2)$$

2.  **Rotational Kinetic Energy:**
    $$T_{p, rot} = \frac{1}{2} I \dot{\theta}^2$$
    Where $I$ is the moment of inertia of the pendulum about its center of mass. For a uniform rod of mass $m$ and total length $L = 2l$, the standard result about the centre is
    $$I = \frac{1}{12}mL^2 = \frac{1}{12}m(2l)^2 = \frac{1}{3}ml^2$$
    Combined with the parallel-axis shift to the pivot this gives $I + ml^2 = \frac{4}{3}ml^2$, the moment of inertia about the pivot used throughout.

Total kinetic energy of the pendulum:
$$T_{pendulum} = \frac{1}{2} m (\dot{x}^2 + 2 l \dot{x} \dot{\theta} \cos(\theta) + l^2 \dot{\theta}^2) + \frac{1}{2} I \dot{\theta}^2$$

### Total Kinetic Energy
Summing the cart and pendulum kinetic energies:
$$T = \frac{1}{2} M \dot{x}^2 + \frac{1}{2} m \dot{x}^2 + m l \dot{x} \dot{\theta} \cos(\theta) + \frac{1}{2} m l^2 \dot{\theta}^2 + \frac{1}{2} I \dot{\theta}^2$$
$$T = \frac{1}{2} (M + m) \dot{x}^2 + m l \dot{x} \dot{\theta} \cos(\theta) + \frac{1}{2} (m l^2 + I) \dot{\theta}^2$$

Since $I = \frac{1}{3} m l^2$, the term $(m l^2 + I)$ evaluates to $m l^2 + \frac{1}{3} m l^2 = \frac{4}{3} m l^2$. Therefore, the total kinetic energy is:
$$T = \frac{1}{2} (M + m) \dot{x}^2 + m l \dot{x} \dot{\theta} \cos(\theta) + \frac{2}{3} m l^2 \dot{\theta}^2$$

## 2.2 Potential Energy ($V$)

The potential energy of the system depends entirely on gravity (assuming no springs). Since the cart moves only horizontally, its height does not change, meaning its potential energy is constant. We can define the reference height ($V=0$) at the track level ($y=0$).

The potential energy of the pendulum depends on the vertical height of its center of mass ($y_p$).
From the kinematics section, $y_p = l \cos(\theta)$.

Therefore, the potential energy is:
$$V = m g y_p = m g l \cos(\theta)$$

## 2.3 The Lagrangian ($L$)

The Lagrangian $L$ is defined as the difference between kinetic and potential energy:
$$L = T - V$$

Substituting our expressions for $T$ and $V$:
$$L = \left[ \frac{1}{2} (M + m) \dot{x}^2 + m l \dot{x} \dot{\theta} \cos(\theta) + \frac{2}{3} m l^2 \dot{\theta}^2 \right] - \left[ m g l \cos(\theta) \right]$$

$$L = \frac{1}{2} (M + m) \dot{x}^2 + m l \dot{x} \dot{\theta} \cos(\theta) + \frac{2}{3} m l^2 \dot{\theta}^2 - m g l \cos(\theta)$$

This Lagrangian fully describes the dynamics of the conservative parts of our system. Next, we will apply the Euler-Lagrange equations to find the equations of motion.

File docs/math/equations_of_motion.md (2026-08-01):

# 3. Euler-Lagrange Equations of Motion

We use the Euler-Lagrange equation to derive the equations of motion for the system's two generalized coordinates: cart position $x$, and pendulum angle $\theta$.

The Euler-Lagrange equation is:
$$\frac{d}{dt} \left( \frac{\partial L}{\partial \dot{q}_i} \right) - \frac{\partial L}{\partial q_i} = Q_i$$
Where $q_i \in \{x, \theta\}$ and $Q_i$ represents the generalized non-conservative forces acting on that coordinate.

The Lagrangian derived in the previous section is:
$$L = \frac{1}{2} (M + m) \dot{x}^2 + m l \dot{x} \dot{\theta} \cos(\theta) + \frac{2}{3} m l^2 \dot{\theta}^2 - m g l \cos(\theta)$$

## 3.1 Equation for the Cart Position ($x$)

The generalized non-conservative force for the cart is the external motor force $F$ minus the viscous friction of the track $b_c \dot{x}$.
$$Q_x = F - b_c \dot{x}$$

**Step 1: Calculate $\frac{\partial L}{\partial \dot{x}}$**
We differentiate $L$ with respect to $\dot{x}$ (treating all other variables, including $x$, $\theta$, and $\dot{\theta}$, as constants):
$$\frac{\partial L}{\partial \dot{x}} = \frac{\partial}{\partial \dot{x}} \left( \frac{1}{2} (M + m) \dot{x}^2 + m l \dot{x} \dot{\theta} \cos(\theta) \right)$$
$$\frac{\partial L}{\partial \dot{x}} = (M + m) \dot{x} + m l \dot{\theta} \cos(\theta)$$
*(Physically, this represents the total linear momentum of the system in the $x$ direction).*

**Step 2: Calculate the time derivative $\frac{d}{dt} \left( \frac{\partial L}{\partial \dot{x}} \right)$**
We take the full time derivative. We must use the product rule on the term $m l \dot{\theta} \cos(\theta)$, because both $\dot{\theta}$ and $\cos(\theta)$ depend on time $t$.
$$\frac{d}{dt} \left( \frac{\partial L}{\partial \dot{x}} \right) = \frac{d}{dt} [ (M + m) \dot{x} ] + \frac{d}{dt} [ m l \dot{\theta} \cos(\theta) ]$$
$$\frac{d}{dt} \left( \frac{\partial L}{\partial \dot{x}} \right) = (M + m) \ddot{x} + m l \ddot{\theta} \cos(\theta) + m l \dot{\theta} \left( \frac{d}{dt} \cos(\theta) \right)$$
Using the chain rule, $\frac{d}{dt} \cos(\theta) = -\sin(\theta) \dot{\theta}$:
$$\frac{d}{dt} \left( \frac{\partial L}{\partial \dot{x}} \right) = (M + m) \ddot{x} + m l \ddot{\theta} \cos(\theta) - m l \dot{\theta}^2 \sin(\theta)$$

**Step 3: Calculate $\frac{\partial L}{\partial x}$**
Since $x$ does not explicitly appear in the Lagrangian $L$, this term is zero:
$$\frac{\partial L}{\partial x} = 0$$

**Step 4: Assemble the equation**
$$ \left( (M + m) \ddot{x} + m l \ddot{\theta} \cos(\theta) - m l \dot{\theta}^2 \sin(\theta) \right) - (0) = F - b_c \dot{x} $$

**Final Translational Equation of Motion:**
$$(M + m)\ddot{x} + ml\ddot{\theta}\cos(\theta) - ml\dot{\theta}^2\sin(\theta) = F - b_c\dot{x}$$

## 3.2 Equation for the Pendulum Angle ($\theta$)

The generalized non-conservative force for the pendulum is the viscous friction at the pivot joint $b_p \dot{\theta}$. Since friction opposes motion, it acts in the negative direction.
$$Q_\theta = -b_p \dot{\theta}$$

**Step 1: Calculate $\frac{\partial L}{\partial \dot{\theta}}$**
We differentiate $L$ with respect to $\dot{\theta}$:
$$\frac{\partial L}{\partial \dot{\theta}} = \frac{\partial}{\partial \dot{\theta}} \left( m l \dot{x} \dot{\theta} \cos(\theta) + \frac{2}{3} m l^2 \dot{\theta}^2 \right)$$
$$\frac{\partial L}{\partial \dot{\theta}} = m l \dot{x} \cos(\theta) + \frac{4}{3} m l^2 \dot{\theta}$$
*(Physically, this represents the angular momentum of the system).*

**Step 2: Calculate the time derivative $\frac{d}{dt} \left( \frac{\partial L}{\partial \dot{\theta}} \right)$**
Taking the full time derivative, using the product rule on $m l \dot{x} \cos(\theta)$:
$$\frac{d}{dt} \left( \frac{\partial L}{\partial \dot{\theta}} \right) = m l \ddot{x} \cos(\theta) + m l \dot{x} (-\sin(\theta) \dot{\theta}) + \frac{4}{3} m l^2 \ddot{\theta}$$
$$\frac{d}{dt} \left( \frac{\partial L}{\partial \dot{\theta}} \right) = m l \ddot{x} \cos(\theta) - m l \dot{x} \dot{\theta} \sin(\theta) + \frac{4}{3} m l^2 \ddot{\theta}$$

**Step 3: Calculate $\frac{\partial L}{\partial \theta}$**
We differentiate $L$ with respect to $\theta$. The variable $\theta$ appears inside $\cos(\theta)$ in two terms:
$$\frac{\partial L}{\partial \theta} = \frac{\partial}{\partial \theta} \left( m l \dot{x} \dot{\theta} \cos(\theta) - m g l \cos(\theta) \right)$$
$$\frac{\partial L}{\partial \theta} = -m l \dot{x} \dot{\theta} \sin(\theta) + m g l \sin(\theta)$$

**Step 4: Assemble the equation**
$$ \left( m l \ddot{x} \cos(\theta) - m l \dot{x} \dot{\theta} \sin(\theta) + \frac{4}{3} m l^2 \ddot{\theta} \right) - \left( -m l \dot{x} \dot{\theta} \sin(\theta) + m g l \sin(\theta) \right) = -b_p \dot{\theta} $$

Notice that the Coriolis term $-m l \dot{x} \dot{\theta} \sin(\theta)$ cancels out beautifully:
$$m l \ddot{x} \cos(\theta) - m l \dot{x} \dot{\theta} \sin(\theta) + \frac{4}{3} m l^2 \ddot{\theta} + m l \dot{x} \dot{\theta} \sin(\theta) - m g l \sin(\theta) = -b_p \dot{\theta}$$
$$m l \ddot{x} \cos(\theta) + \frac{4}{3} m l^2 \ddot{\theta} - m g l \sin(\theta) = -b_p \dot{\theta}$$

**Final Rotational Equation of Motion:**
$$ml\ddot{x}\cos(\theta) + \frac{4}{3}ml^2\ddot{\theta} - mgl\sin(\theta) = -b_p\dot{\theta}$$

## 3.3 Summary of Non-Linear System Equations
1. **Translational:** $(M + m)\ddot{x} + ml\ddot{\theta}\cos(\theta) - ml\dot{\theta}^2\sin(\theta) = F - b_c\dot{x}$
2. **Rotational:** $ml\ddot{x}\cos(\theta) + \frac{4}{3}ml^2\ddot{\theta} - mgl\sin(\theta) = -b_p\dot{\theta}$

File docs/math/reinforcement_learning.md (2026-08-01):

# 5. Reinforcement Learning Formulation

In addition to classical control methods (like LQR and PID), this project utilizes Reinforcement Learning (RL) to stabilize and swing up the inverted pendulum. Specifically, we employ Proximal Policy Optimization (PPO) and Soft Actor-Critic (SAC).

This document outlines the mathematical formulation of the RL environment and the core equations for these algorithms.

## 5.1 Markov Decision Process (MDP)

The inverted pendulum problem is formulated as a continuous-time Markov Decision Process (MDP) defined by the tuple $(\mathcal{S}, \mathcal{A}, \mathcal{P}, \mathcal{R}, \gamma)$.

### State Space ($\mathcal{S}$)
The state vector $s_t \in \mathcal{S}$ is continuous and contains the kinematic variables of the cart and pendulum:
$$s_t = \begin{bmatrix} x \\ \dot{x} \\ \theta \\ \dot{\theta} \end{bmatrix}$$
Where $x$ is cart position, $\dot{x}$ is cart velocity, $\theta$ is pendulum angle, and $\dot{\theta}$ is angular velocity. (Note: In some implementations, $\theta$ is represented as $[\cos(\theta), \sin(\theta)]$ to avoid discontinuity at $\pi \equiv -\pi$).

### Action Space ($\mathcal{A}$)
The action $a_t \in \mathcal{A}$ is continuous and represents the force or voltage applied to the cart motor:
$$a_t = F \in [F_{min}, F_{max}]$$

### Transition Dynamics ($\mathcal{P}$)
The transition probability density $P(s_{t+1} | s_t, a_t)$ is determined by the non-linear physics of the system (derived in previous sections) integrated over a discrete time step $\Delta t$. Using numerical integration (e.g., Euler or Runge-Kutta 4):
$$s_{t+1} = s_t + \int_{t}^{t+\Delta t} f_{physics}(s, a) dt$$

### Reward Function ($\mathcal{R}$)
The reward function $r_t = R(s_t, a_t)$ is designed to penalize deviation from the upright equilibrium ($\theta=0, x=0$) and penalize excessive control effort. A typical quadratic reward formulation is:
$$r_t = -(Q_{\theta} \theta^2 + Q_{x} x^2 + Q_{\dot{\theta}} \dot{\theta}^2 + Q_{\dot{x}} \dot{x}^2 + R_{u} a_t^2)$$
For swing-up tasks, additional non-linear terms like $\cos(\theta)$ may be used:
$$r_t = \cos(\theta) - 1 - \alpha a_t^2$$

### Discount Factor ($\gamma$)
The discount factor $\gamma \in (0, 1)$ balances immediate and future rewards in the return $R_t$:
$$R_t = \sum_{k=0}^{\infty} \gamma^k r_{t+k}$$

---

## 5.2 Proximal Policy Optimization (PPO) Math

PPO is an on-policy actor-critic algorithm that optimizes the policy by taking steps that are bounded to avoid destructively large updates.

### 1. Advantage Function
PPO uses the Advantage function $A^{\pi}(s, a)$, which measures how much better an action $a$ is compared to the average action in state $s$:
$$A_t = Q_t(s_t, a_t) - V_t(s_t)$$
In practice, this is estimated using Generalized Advantage Estimation (GAE).

### 2. Probability Ratio
Let $\pi_{\theta}(a_t|s_t)$ be the current policy network and $\pi_{\theta_{old}}(a_t|s_t)$ be the policy network before the update. The probability ratio is:
$$r_t(\theta) = \frac{\pi_{\theta}(a_t|s_t)}{\pi_{\theta_{old}}(a_t|s_t)}$$

### 3. Clipped Surrogate Objective
To prevent large policy updates, PPO clips this ratio. The objective function $L^{CLIP}(\theta)$ that PPO maximizes is:
$$L^{CLIP}(\theta) = \mathbb{E}_t \left[ \min \left( r_t(\theta) A_t, \text{clip}(r_t(\theta), 1-\epsilon, 1+\epsilon) A_t \right) \right]$$
Where $\epsilon$ is a hyperparameter (e.g., 0.2).
*   If $A_t > 0$ (action was good), the ratio is capped at $1+\epsilon$ to prevent over-updating.
*   If $A_t < 0$ (action was bad), the ratio is floored at $1-\epsilon$.

### 4. Value Function Loss
The critic network (value function $V_{\phi}(s_t)$) is updated by minimizing the Mean Squared Error against the targeted returns $R_t$:
$$L^{VF}(\phi) = \mathbb{E}_t \left[ (V_{\phi}(s_t) - R_t)^2 \right]$$

---

## 5.3 Soft Actor-Critic (SAC) Math

SAC is an off-policy algorithm based on the maximum entropy framework. It encourages exploration by maximizing both the expected return and the entropy of the policy.

### 1. Maximum Entropy Objective
The optimal policy $\pi^*$ in SAC maximizes the standard return plus an entropy term $\mathcal{H}$:
$$\pi^* = \arg\max_{\pi} \mathbb{E}_{\tau \sim \pi} \left[ \sum_{t=0}^{\infty} \gamma^t \left( r(s_t, a_t) + \alpha \mathcal{H}(\pi(\cdot | s_t)) \right) \right]$$
Where $\alpha$ is the temperature parameter that determines the relative importance of the entropy term.
The entropy is $\mathcal{H}(\pi(\cdot | s_t)) = -\mathbb{E}_{a \sim \pi} [\log \pi(a|s_t)]$.

### 2. Soft Q-Function Training
The Soft Q-function $Q_{\theta}(s, a)$ is trained to minimize the Soft Bellman Residual:
$$J_Q(\theta) = \mathbb{E}_{(s_t, a_t) \sim \mathcal{D}} \left[ \frac{1}{2} \left( Q_{\theta}(s_t, a_t) - y_t \right)^2 \right]$$
Where the target $y_t$ incorporates the entropy of the next state:
$$y_t = r(s_t, a_t) + \gamma \mathbb{E}_{a_{t+1} \sim \pi_{\phi}} \left[ Q_{\bar{\theta}}(s_{t+1}, a_{t+1}) - \alpha \log \pi_{\phi}(a_{t+1} | s_{t+1}) \right]$$
Here, $Q_{\bar{\theta}}$ is the target Q-network.

### 3. Policy (Actor) Training
The policy network $\pi_{\phi}$ is trained to maximize the Q-value while maintaining high entropy. By applying the reparameterization trick ($a_t = f_{\phi}(\epsilon_t ; s_t)$), the objective to minimize is:
$$J_{\pi}(\phi) = \mathbb{E}_{s_t \sim \mathcal{D}, \epsilon_t \sim \mathcal{N}} \left[ \alpha \log \pi_{\phi}(f_{\phi}(\epsilon_t; s_t) | s_t) - Q_{\theta}(s_t, f_{\phi}(\epsilon_t; s_t)) \right]$$

### 4. Temperature ($\alpha$) Auto-Tuning
In modern SAC, $\alpha$ is automatically adjusted to meet a target entropy $\bar{\mathcal{H}}$:
$$J(\alpha) = \mathbb{E}_{a_t \sim \pi} \left[ -\alpha \log \pi(a_t | s_t) - \alpha \bar{\mathcal{H}} \right]$$

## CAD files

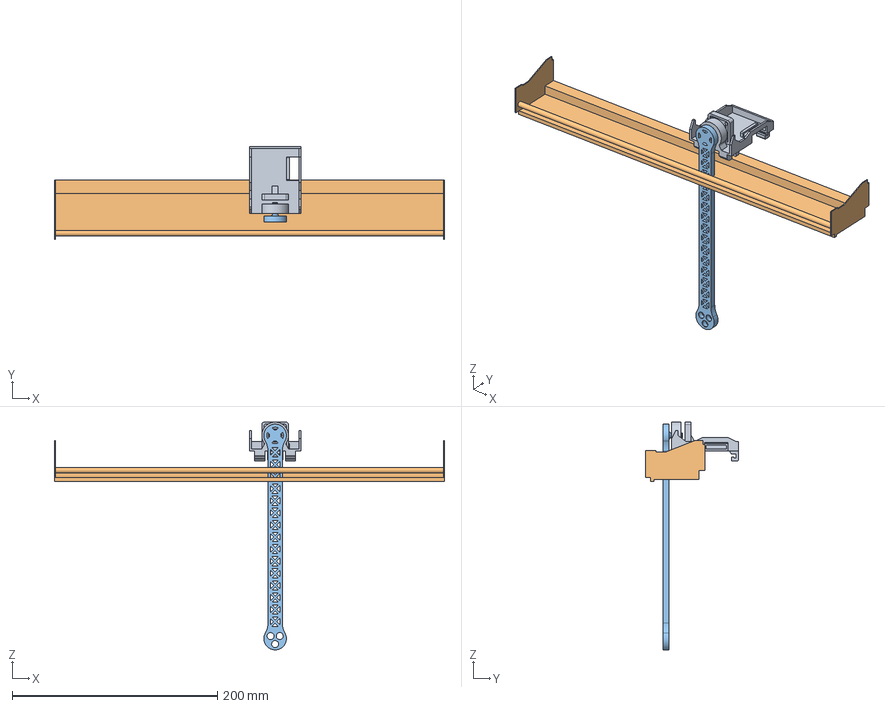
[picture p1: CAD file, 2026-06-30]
models/assembly_model.FCStd
380.0 x 90.5 x 222.0 mm
Cart
Linear Rail
Pendulum

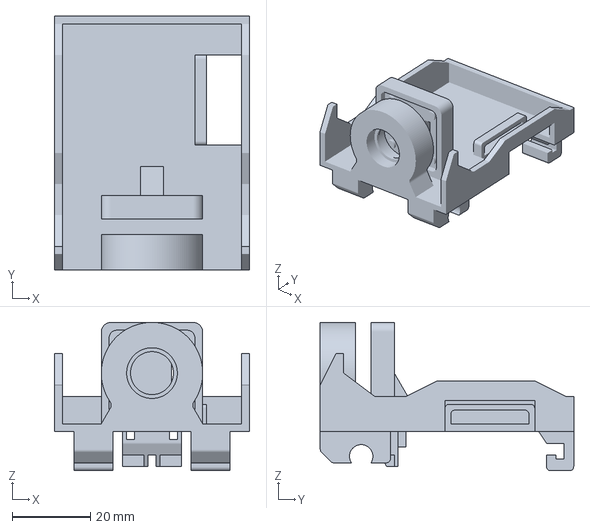
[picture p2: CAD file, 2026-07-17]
models/cart/cart_model.3mf
50.0 x 65.0 x 38.0 mm

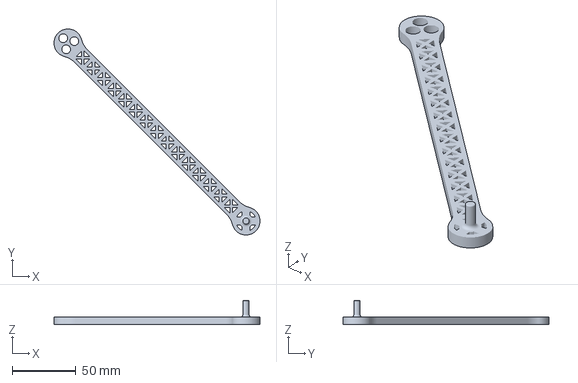
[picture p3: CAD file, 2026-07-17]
models/pendulum/pendulum_model.3mf
162.0 x 162.0 x 19.0 mm

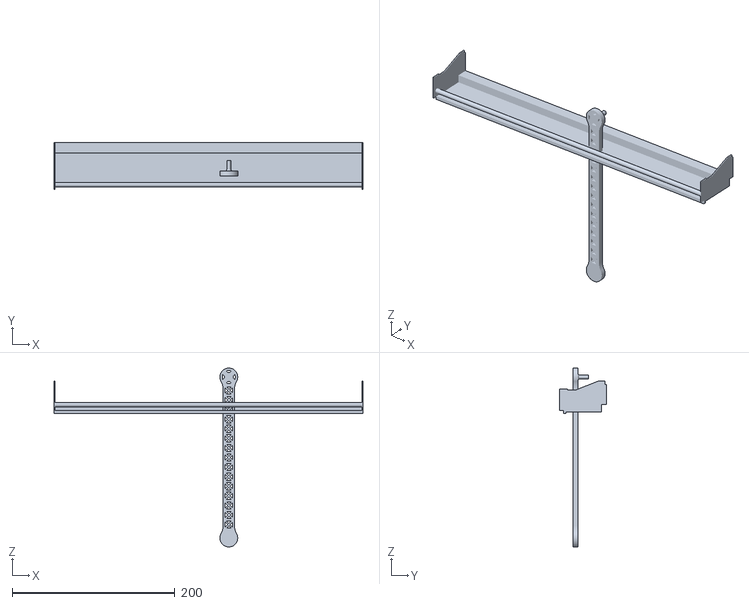
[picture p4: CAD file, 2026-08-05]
models/track_model.stl
380.0 x 58.0 x 220.0

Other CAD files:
models/cart/cart_model.stl
models/pendulum/pendulum_model.stl

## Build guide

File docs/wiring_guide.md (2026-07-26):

# TB6612FNG & AS5600 Wiring Guide

This document outlines the physical wiring and connections between the **ESP32 Microcontroller**, the **AS5600 Magnetic Angle Encoder**, the **TB6612FNG Dual H-Bridge Motor Driver**, and the DC Gearmotor.

---

## 📌 Pinout Summary Table

| Device / Pin | ESP32 GPIO Pin | Description / Notes |
| :--- | :--- | :--- |
| **AS5600 SDA** | `GPIO 22` | I2C Data Line (with internal/external pull-up) |
| **AS5600 SCL** | `GPIO 23` | I2C Clock Line (with internal/external pull-up) |
| **TB6612FNG AIN1**| `GPIO 25` | Motor Direction Pin 1 |
| **TB6612FNG AIN2**| `GPIO 26` | Motor Direction Pin 2 |
| **TB6612FNG PWMA**| `GPIO 27` | Motor Speed (LEDC PWM @ 1 kHz; compatible with Core v2.x & v3.0+) |
| **TB6612FNG STBY**| `GPIO 33` | Driver Standby Control (`HIGH` = Active, `LOW` = Standby/Sleep) |
| **TB6612FNG VCC** | `3.3V` | Logic Voltage Supply (MUST match ESP32 logic voltage) |
| **TB6612FNG GND** | `GND` | Common Ground (Tie ESP32 GND, TB6612 GND, and Motor Battery GND together) |
| **TB6612FNG VM**  | *External 6V–12V* | Motor Power Supply (Do **NOT** connect to ESP32 3.3V or 5V!) |
| **TB6612FNG AO1** | *Motor Term A* | H-Bridge Output 1 to DC Gearmotor |
| **TB6612FNG AO2** | *Motor Term B* | H-Bridge Output 2 to DC Gearmotor |

---

## ⚡ System Wiring Diagram

```
         ESP32 MICROCONTROLLER                   TB6612FNG DRIVER                 DC GEARMOTOR
       ┌───────────────────────┐             ┌──────────────────────┐           ┌──────────────┐
       │                       │             │                      │           │              │
       │                  3.3V ├────────────►│ VCC (Logic Power)    │           │              │
       │                       │             │                      │           │              │
       │                   GND ├────────────►│ GND (Logic & Motor)  │◄──────────┼─ Battery GND │
       │                       │             │                      │           │              │
       │               GPIO 25 ├────────────►│ AIN1 (Dir 1)         │           │              │
       │               GPIO 26 ├────────────►│ AIN2 (Dir 2)         │           │              │
       │               GPIO 27 ├────────────►│ PWMA (PWM Speed)     │           │              │
       │               GPIO 33 ├────────────►│ STBY (Standby HIGH)  │           │              │
       │                       │             │                      │           │              │
       │                       │             │                   VM │◄──────────┼─ Battery + (6-12V)
       │                       │             │                      │           │              │
       │                       │             │                  AO1 ├──────────►│ Terminal +   │
       │                       │             │                  AO2 ├──────────►│ Terminal -   │
       └───────────┬───────────┘             └──────────────────────┘           └──────────────┘
                   │
                   │ (I2C Bus @ 400 kHz)
                   │
       ┌───────────▼───────────┐
       │                       │
       │        AS5600         │
       │   MAGNETIC ENCODER    │
       │                       │
       │  SDA ◄────► GPIO 22   │
       │  SCL ◄────► GPIO 23   │
       │  VCC ◄────► 3.3V      │
       │  GND ◄────► GND       │
       └───────────────────────┘
```

> [!CAUTION]
> **NEVER** connect the motor battery voltage (**VM**, typically 6V to 12V) to the ESP32 `3.3V`, `5V`, or any GPIO pin. Doing so will permanently destroy the microcontroller. Ensure all ground lines (`GND`) from the ESP32, TB6612FNG, and external power supply are tied together into a single common ground reference.

---

## 🔄 Motor H-Bridge Truth Table

| AIN1 | AIN2 | PWMA Duty Cycle | H-Bridge State | Physical Cart Motion |
| :---: | :---: | :---: | :--- | :--- |
| `HIGH` | `LOW` | `1` .. `255` | **Forward** | Cart translates Left (or positive X direction) |
| `LOW` | `HIGH` | `1` .. `255` | **Reverse** | Cart translates Right (or negative X direction) |
| `HIGH` | `HIGH` | `0` | **Hard Brake** | Motor short-circuits to lock position immediately |
| `LOW` | `LOW` | `0` | **Coast** | Motor open-circuits and free-wheels with minimum resistance |

---

## 🛠️ Verification & Testing

To test the physical wiring before running the full control host:
1. Flash the `esp32_endpoint.ino` sketch onto the ESP32.
2. Open terminal or Arduino Serial Monitor at **115200 baud**.
3. Verify that calibrated angle telemetry floats are streaming at 100 Hz.
4. Type `M,100` and hit Enter $\rightarrow$ The motor should gently spin forward.
5. Type `M,-100` and hit Enter $\rightarrow$ The motor should spin reverse.
6. Type `B` and hit Enter $\rightarrow$ The motor should brake instantly.

> [!TIP]
> **Motor Polarity & "Catch-the-Fall" Balancing:**
> Depending on how your motor wires (`AO1`/`AO2`) are connected to the DC gearmotor terminals, sending positive PWM (`M,100`) may move the cart left or right. To balance an inverted pendulum, whenever the rod falls in one direction, the cart MUST accelerate in that exact same direction to catch it and push the base back under the center of gravity. If your cart moves away from the falling rod during auto-balancing, simply check or uncheck the **Reverse Motor Direction** checkbox (`chk_invert_motor`) in the GUI Control Panel. This instantly flips the PWM sign in software ($u = -u$), providing 1-click polarity correction without touching physical wires!

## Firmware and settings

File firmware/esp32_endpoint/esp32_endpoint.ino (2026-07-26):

/**
 * Inverted Pendulum ESP32 Hardware-in-the-Loop (HIL) Endpoint v2.0
 * 
 * Modular C++ firmware for the ESP32 microcontroller. Acts as an ultra-fast,
 * low-latency I/O server that streams calibrated AS5600 12-bit angle telemetry
 * over USB Serial (115200 baud) and actuates the TB6612FNG H-bridge motor driver.
 * 
 * All closed-loop balancing algorithms (PID, LQR, Energy Swing-Up) reside on the
 * Python PC host for zero-recompile experimentation and Reinforcement Learning.
 */

#include <Arduino.h>
#include "config.h"
#include "encoder_driver.h"
#include "motor_driver.h"
#include "serial_parser.h"

EncoderDriver encoder;
MotorDriver motor;
uint16_t telemetryRateHz = DEFAULT_TELEMETRY_HZ;
SerialParser parser(encoder, motor, telemetryRateHz);

unsigned long lastTelemetryUs = 0;

void setup() {
    Serial.begin(SERIAL_BAUD_RATE);
    while (!Serial && millis() < 2000); // Allow USB CDC serial settling

    // Initialize motor GPIO and LEDC PWM channels
    motor.begin();

    // Initialize I2C bus and AS5600 magnetic encoder
    bool encoderOk = encoder.begin();
    if (!encoderOk) {
        Serial.println("[WARNING] AS5600 sensor not detected on I2C bus! Check SDA (GPIO22) & SCL (GPIO23).");
    } else {
        Serial.println("[READY] Inverted Pendulum ESP32 HIL Endpoint v2.0 initialized successfully.");
    }
}

void loop() {
    // 1) Non-blockingly poll and execute incoming USB serial commands (M, F, R, B, C, T, Q, Z)
    parser.poll();

    // 2) Stream high-frequency ASCII angle telemetry at the configured rate
    if (telemetryRateHz > 0) {
        unsigned long intervalUs = 1000000UL / telemetryRateHz;
        unsigned long nowUs = micros();
        
        if (nowUs - lastTelemetryUs >= intervalUs) {
            lastTelemetryUs = nowUs;
            float angle = encoder.getCalibratedAngle();
            Serial.println(angle, 2);
        }
    }
}

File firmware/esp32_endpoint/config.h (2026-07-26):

#ifndef CONFIG_H
#define CONFIG_H

#include <Arduino.h>

// ─── Serial Communication Settings ───
#define SERIAL_BAUD_RATE      115200
#define DEFAULT_TELEMETRY_HZ  100
#define MAX_TELEMETRY_HZ      1000

// ─── AS5600 Magnetic Encoder (I2C) Pin Mapping ───
#define PIN_I2C_SDA           22
#define PIN_I2C_SCL           23
#define AS5600_I2C_ADDR       0x36
#define AS5600_REG_ANGLE_H    0x0E
#define AS5600_REG_ANGLE_L    0x0F

// ─── TB6612FNG Motor Driver Pin Mapping ───
#define PIN_MOTOR_AIN1        25
#define PIN_MOTOR_AIN2        26
#define PIN_MOTOR_PWMA        27
#define PIN_MOTOR_STBY        33

// ─── ESP32 LEDC PWM Settings ───
#define LEDC_TIMER_BIT_RES    8        // 8-bit resolution (0-255 PWM duty cycle)
#define LEDC_BASE_FREQ_HZ     1000     // 1 kHz PWM frequency for smooth motor actuation
#define LEDC_PWM_CHANNEL      0        // ESP32 LEDC Channel 0

// ─── Safety and Deadband Limits ───
#define MIN_PWM_POWER         45       // Minimum duty cycle to overcome static motor friction
#define MAX_PWM_POWER         255      // Maximum duty cycle

#endif // CONFIG_H

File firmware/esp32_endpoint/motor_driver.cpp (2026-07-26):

#include "motor_driver.h"

#if __has_include(<esp_arduino_version.h>)
#include <esp_arduino_version.h>
#endif

MotorDriver::MotorDriver() : _currentPower(0) {}

// Helper function to handle PWM write differences between ESP32 Core v2.x and v3.x
inline void writeMotorPWM(int duty) {
#if defined(ESP_ARDUINO_VERSION_MAJOR) && (ESP_ARDUINO_VERSION_MAJOR >= 3)
    // In ESP32 Arduino Core v3.0+, ledcWrite takes the GPIO pin number
    ledcWrite(PIN_MOTOR_PWMA, duty);
#else
    // In legacy ESP32 Arduino Core v2.x, ledcWrite takes the LEDC channel number
    ledcWrite(LEDC_PWM_CHANNEL, duty);
#endif
}

void MotorDriver::begin() {
    pinMode(PIN_MOTOR_AIN1, OUTPUT);
    pinMode(PIN_MOTOR_AIN2, OUTPUT);
    pinMode(PIN_MOTOR_STBY, OUTPUT);

    // Enable TB6612FNG H-bridge standby pin
    digitalWrite(PIN_MOTOR_STBY, HIGH);

    // Configure ESP32 LEDC PWM timer (compatible with both Core v2.x and Core v3.x)
#if defined(ESP_ARDUINO_VERSION_MAJOR) && (ESP_ARDUINO_VERSION_MAJOR >= 3)
    // ESP32 Arduino Core v3.0+ API (ESP-IDF v5.x)
    ledcAttach(PIN_MOTOR_PWMA, LEDC_BASE_FREQ_HZ, LEDC_TIMER_BIT_RES);
#else
    // Legacy ESP32 Arduino Core v2.x API (ESP-IDF v4.x)
    ledcSetup(LEDC_PWM_CHANNEL, LEDC_BASE_FREQ_HZ, LEDC_TIMER_BIT_RES);
    ledcAttachPin(PIN_MOTOR_PWMA, LEDC_PWM_CHANNEL);
#endif

    coast();
}

void MotorDriver::setPower(int power) {
    power = constrain(power, -MAX_PWM_POWER, MAX_PWM_POWER);
    _currentPower = power;

    if (power == 0) {
        coast();
    } else if (power > 0) {
        forward(power);
    } else {
        reverse(-power);
    }
}

void MotorDriver::forward(int speed) {
    speed = constrain(speed, 0, MAX_PWM_POWER);
    digitalWrite(PIN_MOTOR_AIN1, HIGH);
    digitalWrite(PIN_MOTOR_AIN2, LOW);
    writeMotorPWM(speed);
}

void MotorDriver::reverse(int speed) {
    speed = constrain(speed, 0, MAX_PWM_POWER);
    digitalWrite(PIN_MOTOR_AIN1, LOW);
    digitalWrite(PIN_MOTOR_AIN2, HIGH);
    writeMotorPWM(speed);
}

void MotorDriver::brake() {
    _currentPower = 0;
    digitalWrite(PIN_MOTOR_AIN1, HIGH);
    digitalWrite(PIN_MOTOR_AIN2, HIGH);
    writeMotorPWM(MAX_PWM_POWER);
}

void MotorDriver::coast() {
    _currentPower = 0;
    digitalWrite(PIN_MOTOR_AIN1, LOW);
    digitalWrite(PIN_MOTOR_AIN2, LOW);
    writeMotorPWM(0);
}

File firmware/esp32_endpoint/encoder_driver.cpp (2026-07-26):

#include "encoder_driver.h"

EncoderDriver::EncoderDriver() : _zeroOffsetDeg(0.0f), _initialized(false) {}

bool EncoderDriver::begin() {
    Wire.begin(PIN_I2C_SDA, PIN_I2C_SCL);
    Wire.setClock(400000); // 400 kHz Fast I2C Mode for minimum latency
    
    // Check if AS5600 responds on I2C bus
    Wire.beginTransmission(AS5600_I2C_ADDR);
    byte error = Wire.endTransmission();
    
    if (error != 0) {
        return false;
    }
    
    _sensor.begin(); // Initialize official AS5600 library
    _initialized = true;
    
    // Wait 2.5 seconds to let power rails stabilize and pendulum motionless settling
    Serial.println("[CALIBRATION] Waiting 2.5s for pendulum to settle before zeroing...");
    delay(2500);
    Serial.println("[CALIBRATION] Sampling hanging zero equilibrium (300 samples)...");
    tare(300);
    return true;
}

uint16_t EncoderDriver::readRawBits() {
    if (!_initialized) return 0;
    // Use official AS5600 library method for reliable register timing and hysteresis handling
    return _sensor.readAngle();
}

float EncoderDriver::readRawAngleDeg() {
    uint16_t bits = readRawBits();
    return (float)bits * (360.0f / 4096.0f);
}

float EncoderDriver::getCalibratedAngle() {
    float rawDeg = readRawAngleDeg();
    float angle = rawDeg - _zeroOffsetDeg;
    while (angle < 0.0f) angle += 360.0f;
    while (angle >= 360.0f) angle -= 360.0f;
    return angle;
}

float EncoderDriver::tare(int samples) {
    if (!_initialized || samples <= 0) return 0.0f;
    
    float sum = 0.0f;
    for (int i = 0; i < samples; i++) {
        sum += readRawAngleDeg();
        delay(10); // 10ms delay per sample for deep noise attenuation and vibration averaging
    }
    _zeroOffsetDeg = sum / (float)samples;
    return _zeroOffsetDeg;
}

void EncoderDriver::setZeroOffset(float offset_deg) {
    _zeroOffsetDeg = offset_deg;
}

float EncoderDriver::getZeroOffset() const {
    return _zeroOffsetDeg;
}

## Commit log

2026-06-30 init(models): created 3D model of hardware assembly
    [Model-Cart.3mf, Model-Cart.stl, Model-Pendulum.3mf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]
2026-07-17 feat(telemetry): recreate CAD-aesthetic PyQt6 dashboard for inverted pendulum
2026-07-17 feat(calibration): add sensor calibration offset, gain, and inversion settings
2026-07-17 feat(twin): convert to pure zero-button digital twin with background scanning and config.json
2026-07-17 feat(logging): print connection events and raw telemetry to console
2026-07-17 feat(aesthetics): switch to white theme, remove neural net, start ticking immediately
2026-07-17 fix(serial): implement main-thread serial polling to fix data reading issue
2026-07-17 feat(telemetry): remove all simulation, show live esp32 encoder angle with velocity calculations
2026-07-17 fix(calibration): use raw ESP32 angles directly without modification
2026-07-17 fix: serial pipeline + real-time telemetry improvements
    - Fix serial reader: timeout 0.001s→0.05s so readline() captures complete lines
    - Remove in_waiting/msleep polling loop that caused line fragmentation
    - Open serial port with DTR=False to prevent ESP32 auto-reset
    - Add wrap-aware angle deviation (-180..+180) for clean sine wave graph
    - Add wrap-aware velocity calculation (no spikes at 0/360 boundary)
    - Add velocity vs time graph, peak metrics, sample rate display
    - Add protractor-style angle markings around pendulum pivot
    - Split rendering: 60 FPS canvas + 20 FPS graph with numpy ring buffers
    - Enable pyqtgraph clipToView + downsampling for performance
2026-07-17 feat: add TB6612FNG motor control, oscillation mode, and auto-calibration
    Firmware:
    - Add TB6612FNG DC motor control logic
    - Migrate to ESP32 Arduino Core 3.x LEDC PWM API
    - Add non-blocking oscillation mode (started via '1'/'0' serial commands)
    - Lower PWM frequency to 1kHz to maximize motor torque
    - Add robust 100-sample startup averaging for precise zero-offset equilibrium
    - Add comprehensive motor driver wiring guide
    GUI:
    - Fix pyqtgraph shape mismatch exception caused by background thread race condition
    - Replace simple pivot dot with a visual cart and horizontal track rail graphic
    [Model-Cart.3mf, Model-Pendulum.3mf]
2026-07-18 Implement manual keyboard control, PID live-tuning, thread-safe serial writing, and horizontal crossing control inversion
2026-07-18 Commit entire updated project: horizontal control inversion firmware, live PID tuning GUI, thread-safe serial writes, and repository cleanup
2026-07-26 refactor(arch): migrate embedded control loop to python HIL station and modularize codebase
    [assembly_model.FCStd, cart_model.3mf, cart_model.stl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]
2026-07-26 fix(firmware): add dual support for ESP32 Arduino Core v2.x and Core v3.0+ LEDC PWM APIs
    [motor_driver.cpp]
2026-07-26 docs: add dual ESP32 Core v2.x and Core v3.0+ PWM API documentation across guides
2026-07-26 fix(firmware): restore high-stability hanging zero calibration with 2.5s settling delay and 300-sample averaging
    [encoder_driver.cpp, serial_parser.cpp]
2026-07-26 fix(hardware): correct AS5600 I2C pin mapping from GPIO22/23 back to standard GPIO21/22
    [config.h, esp32_endpoint.ino]
2026-07-26 fix(firmware): switch AS5600 angle reading to use official library for reliable I2C register access
    [encoder_driver.cpp]
2026-07-26 fix(hardware): restore specified AS5600 I2C pin mapping to SDA=GPIO22 and SCL=GPIO23
    [config.h, esp32_endpoint.ino]
2026-07-26 feat(gui): integrate multi-algorithm HIL mode selector (PID, LQR, RL, Hybrid) and tabbed research charts with Phase Portrait
2026-07-26 fix(gui): correct LQR and Hybrid controller initialization keyword arguments in main_window
    [config.h, encoder_driver.cpp, esp32_endpoint.ino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]
2026-07-26 feat(gui): invert angle reading by default, add sensor transformation checkboxes, and remove emojis from UI
    [control_panel.py, main_window.py]
2026-07-26 revert(gui): revert commit a8a720d to restore un-inverted control logic and prevent rapid motor spinning
    [control_panel.py, main_window.py]
2026-07-26 feat(gui): invert angle for display only without touching control logic and remove emojis
    [control_panel.py, main_window.py]
2026-07-26 fix(gui): use shortest path angle wrapping in [-180, 180] to eliminate chart spikes, clamp velocity, and correct canvas orientation
    [control_panel.py, main_window.py]
2026-07-26 feat(gui): add motor direction reversal toggle checked by default so cart moves in direction of pendulum fall
    [control_panel.py, main_window.py]
2026-07-26 docs: document catch-the-fall motor polarity reversal, GUI toggles, and shortest-path telemetry wrapping
2026-07-26 fix(rl): fix velocity calculation, sign mismatch, and lower hemisphere inversion in RLBalancer
2026-07-26 feat(rl): add -20 negative reward spin penalty for rapid rotation (>360 deg/s) and double quadratic velocity cost
2026-07-26 revert(controllers): restore lower hemisphere inversion to eliminate motor vibration and angle flickering
2026-07-26 fix(comms, controllers): implement 3-tap median and EMA low-pass filtering on angle telemetry and widen deadzone to eliminate sensor noise vibration
    [main_window.py]
2026-07-26 feat(gui): richer dashboard analytics, robust telemetry filtering, reward/metric fixes
    Dashboard:
    - Add RMS error, IAE, mean |PWM| effort, balance-uptime, cumulative
    reward to the metrics panel.
    - Add Performance Analytics tab (error/effort histograms + cumulative
    IAE) and Control-Cost/Reward tab; enhance phase portrait with settling
    ring, fading trail, and head marker.
    - Reflow layout: fixed-width sidebar (viewport + controls) with the wide
    charts/metrics area stretching to fill.
    Telemetry robustness:
    - Add outlier/glitch gate rejecting physically-impossible angle jumps
    (with re-sync escape hatch) to stop AS5600 spikes poisoning state.
    - Adaptive EMA that never freezes, so the ba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
    [main_window.py]
2026-08-01 style: standardize button geometry, typography, and hover transitions across GUI
2026-08-01 style: apply design system button styling to RL Training Studio buttons
2026-08-01 fix: resolve pyqtgraph radius array indexing bug and add CAD STL mesh loader for models/ directory
2026-08-01 fix: resolve cube attribute error with custom MeshData cuboid and enable CAD STL loading
2026-08-01 fix: center STL CAD vertex bounding boxes and align rigid-body 3D pivot rotation
2026-08-01 feat: integrate FreeCAD assembly CAD model loader and refine joint alignment
2026-08-01 feat: explicitly render FreeCAD assembly CAD asset assembly_model.FCStd in 3D viewport
2026-08-01 feat: add automatic FreeCAD assembly script converter for assembly_model.FCStd
2026-08-01 feat: execute FreeCAD 1.1 engine to convert assembly_model.FCStd shapes directly
2026-08-01 feat: extract and render track CAD assembly model alongside cart and pendulum
2026-08-01 feat: add interactive manual cart alignment slider and 100Hz 3D non-linear physics simulation engine
2026-08-05 feat(controllers): implement discrete track balancer controller with unit tests
2026-08-05 feat(gui): add hold-to-drive manual control buttons and speed configuration
2026-08-05 feat(models): add track STL model and update cart and pendulum 3D assets
    [cart_model.stl, pendulum_model.stl, track_model.stl]
